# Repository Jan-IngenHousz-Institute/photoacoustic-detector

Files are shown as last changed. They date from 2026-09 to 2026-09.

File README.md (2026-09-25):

# photoacoustic-detector

Photoacoustic detector built from a TLV320ADC6120 audio ADC shield on a
Raspberry Pi Pico (RP2040), an IM73A135 MEMS microphone, and an
actoPulserX4-48V programmable current source driving a 1900 nm LED
(Ushio SMBB1900D-1100-02).

```
kicad/        shield schematic and PCB (Pico + TLV320ADC6120 + mic connector)
doc/          datasheets (ADC, microphone, TI analog-input app note)
firmware/   MicroPython firmware for the Pico
pc-gui/           PySide6 desktop GUI
```

## Wiring

| Function | Pico pin | Notes |
|---|---|---|
| ADC I2C SDA / SCL | GP4 / GP5 | on the shield, 2k2 pull-ups to 3V3 |
| ADC BCLK / FSYNC / SDOUT| GP6 / GP7 / GP8 | Pico is I2S master, 48 kHz 16-bit stereo |
| ADC GPIO1 ("EXT") | GP9 | unused (ADC interrupt output) |
| actopulser SDA / SCL | GP2 / GP3 | J1 pins 7 / 6, Pico internal pull-ups enabled |
| actopulser LDAC | GP14 | J1 pin 8, held low |
| actopulser PULSEa..d | GP10..GP13 | J1 pins 1..4 |
| GND | GND | J1 pin 5 |

Power the actopulser from its own USB-PD supply, not from the Pico. For the
1.4 V LED select 5 V on the actopulser DIP switch: higher rails only heat the
driver MOSFET.

## Firmware (firmware/)

| File | Purpose |
|---|---|
| `TLV320.py` | TLV320ADC6120 driver (presence check, bring-up, gain, status)  |
| `MCP4728.py` | actopulser DAC driver (0.5 mA per LSB into the 2 ohm sense) |
| `pulser.py` | PIO pulse generator locked to the I2S frame clock |
| `lockin.py` | 100 ms block lock-in (viper), raw block de-interleave |
| `main.py` | application: self-test, serial protocol, safety limits |
| `level_meter.py` | stand-alone level meter for first bring-up (`import level_meter`) |

Install: flash a MicroPython UF2 (hold BOOTSEL while plugging in, copy the
UF2 onto the RPI-RP2 drive), then

```
pip install mpremote
mpremote cp firmware/TLV320.py firmware/MCP4728.py firmware/pulser.py firmware/lockin.py firmware/main.py :
mpremote reset
```

`main.py` starts automatically at boot and speaks a line protocol over USB
serial (see the docstring in `firmware/main.py`). Safety rules enforced on
the Pico: LED current limited to 2 A only for pulses of at most 10 us at
1 % duty and to 1 A otherwise, light switched off when the PC stops sending
commands for 5 s, and on any firmware exception.

## PC GUI (pc-gui/)

```
pc-gui\run_gui.bat
```

or, with any Python 3.10+ that imports PySide6 cleanly:

```
pip install -r pc-gui/requirements.txt
python pc-gui/pa_gui.py
```

Note for anaconda users: the anaconda base interpreter fails with
`DLL load failed while importing QtCore` because its root folder ships MSVC
runtime 14.44 DLLs that shadow the newer runtime PySide6 6.11 needs. Use the
python.org interpreter (`py -3.13`, which `run_gui.bat` does), or install
PySide6 from conda-forge inside a conda environment instead of pip.

What it does:

- finds Picos on USB, flags one left in BOOTSEL mode, checks the firmware
  answers, and runs a layered self-test (ADC ack, register test, reset
  defaults, clock lock, active mode, FSYNC present, mic noise floor,
  DAC ack and readback, optional light on/off signal check);
- excitation control with live duty, LED and driver power, and refusal of
  settings outside the LED rating;
- lock-in amplitude and phase strip charts with block averaging, dark
  reference subtraction, dBFS or pascal units, SNR from the spectrum;
- spectrum with markers at the modulation frequency and harmonics, raw
  time trace and pulse-synchronous average;
- frequency sweep to locate the acoustic resonance of the cell;
- CSV logging with the full settings context, notes, config save/load.

## Measurement principle

The Pico drives the LED with short current pulses at a modulation frequency
that divides 48 kHz. A PIO state machine derives the pulse timing from the
I2S word clock, so every pulse falls on the same sample index and the
lock-in phase is stable. Each 100 ms block of ADC samples holds a whole
number of modulation periods; its single-bin DFT gives amplitude and phase
of the photoacoustic response, which the PC averages, plots and logs.

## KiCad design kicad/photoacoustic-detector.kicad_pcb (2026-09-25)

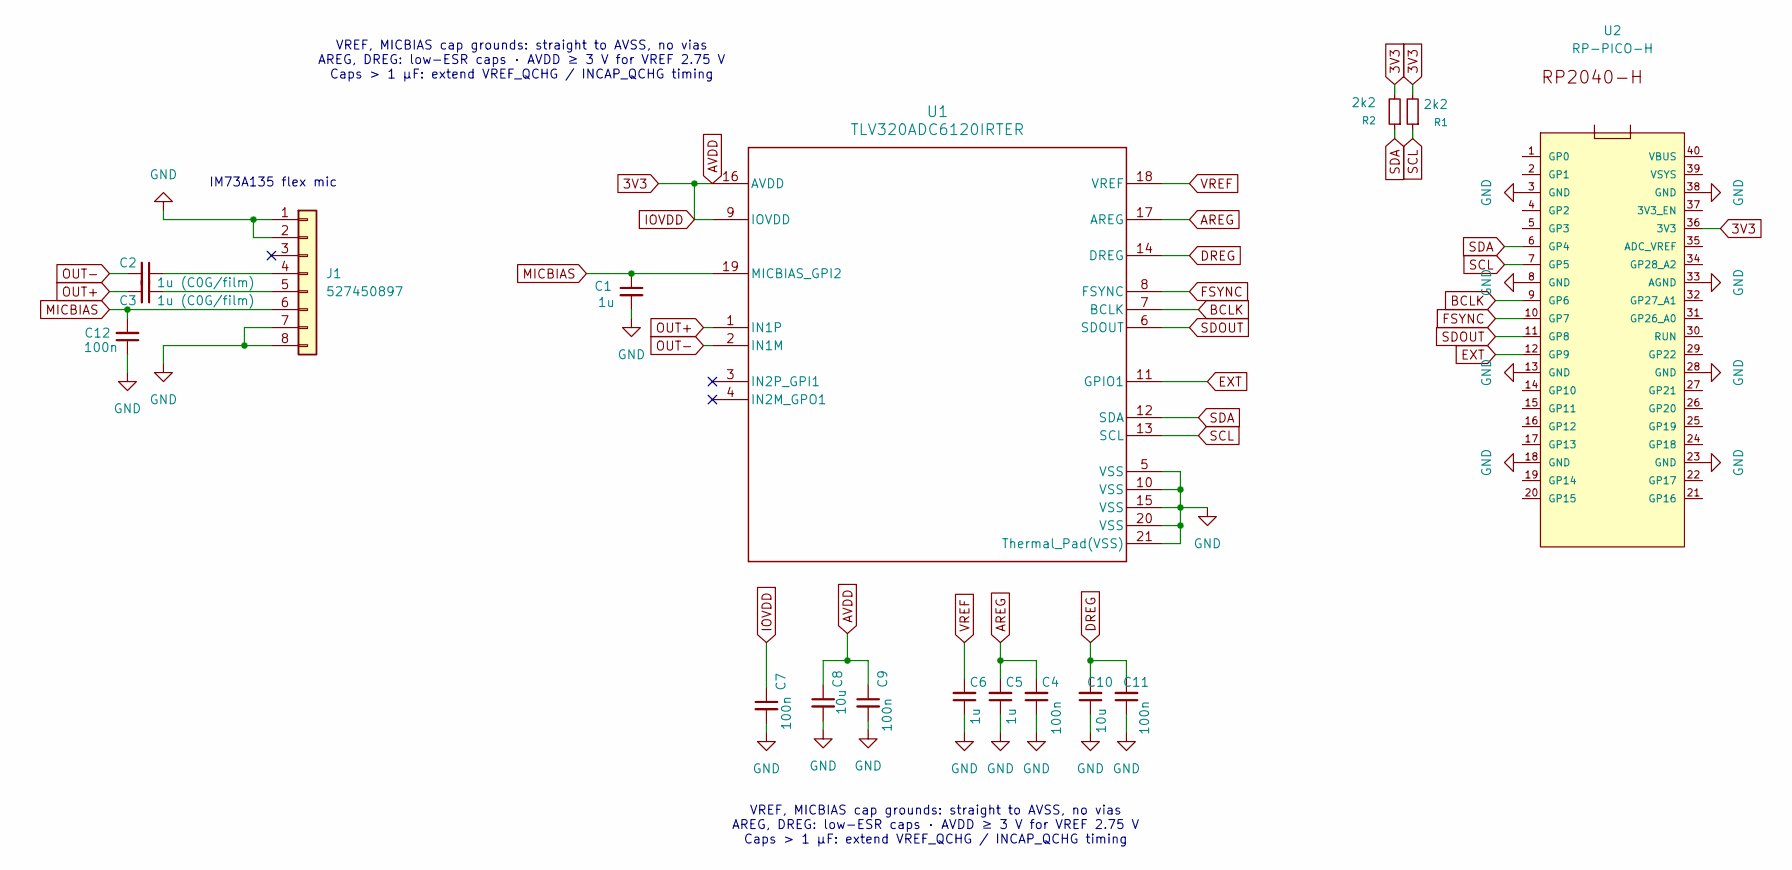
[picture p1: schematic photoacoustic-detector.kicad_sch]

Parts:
C1, C5, C6: 1u; C_0201_0603Metric_Pad0.64x0.40mm_HandSolder
C2, C3: 1u (C0G/film); C_0201_0603Metric_Pad0.64x0.40mm_HandSolder
C4, C7, C9, C11, C12: 100n; C_0201_0603Metric_Pad0.64x0.40mm_HandSolder
C8, C10: 10u; C_0201_0603Metric_Pad0.64x0.40mm_HandSolder
J1: 527450897; CONN_527450897_MOL
R1, R2: 2k2; R_0201_0603Metric_Pad0.64x0.40mm_HandSolder
U1: TLV320ADC6120IRTER; TLV320ADC6120
U2: RP-PICO-H; RP2040-PICO

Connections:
3V3: C7.1, C8.1, C9.1, R1.2, R2.2, U1.9 (IOVDD), U1.16 (AVDD), U2.36 (3V3)
AREG: C4.2, C5.2, U1.17 (AREG)
BCLK: U1.7 (BCLK), U2.9 (GP6)
DREG: C10.2, C11.2, U1.14 (DREG)
EXT: U1.11 (GPIO1), U2.12 (GP9)
FSYNC: U1.8 (FSYNC), U2.10 (GP7)
GND: C1.2, C4.1, C5.1, C6.1, C7.2, C8.2, C9.2, C10.1, C11.1, C12.1, J1.1, J1.2, J1.7, J1.8, U1.5 (VSS), U1.10 (VSS), U1.15 (VSS), U1.20 (VSS), U1.21 (Thermal_Pad(VSS)), U2.3 (GND), U2.8 (GND), U2.13 (GND), U2.18 (GND), U2.23 (GND), U2.28 (GND), U2.33 (AGND), U2.38 (GND)
MICBIAS: C1.1, C12.2, J1.6, U1.19 (MICBIAS_GPI2)
unnamed: C2.1, J1.4
unnamed: C3.1, J1.5
OUT+: C3.2, U1.1 (IN1P)
OUT-: C2.2, U1.2 (IN1M)
SCL: R1.1, U1.13 (SCL), U2.7 (GP5)
SDA: R2.1, U1.12 (SDA), U2.6 (GP4)
SDOUT: U1.6 (SDOUT), U2.11 (GP8)
VREF: C6.2, U1.18 (VREF)

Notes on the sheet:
IM73A135 flex mic
VREF, MICBIAS cap grounds: straight to AVSS, no vias AREG, DREG: low-ESR caps · AVDD ≥ 3 V for VREF 2.75 V Caps > 1 µF: extend VREF_QCHG / INCAP_QCHG timing

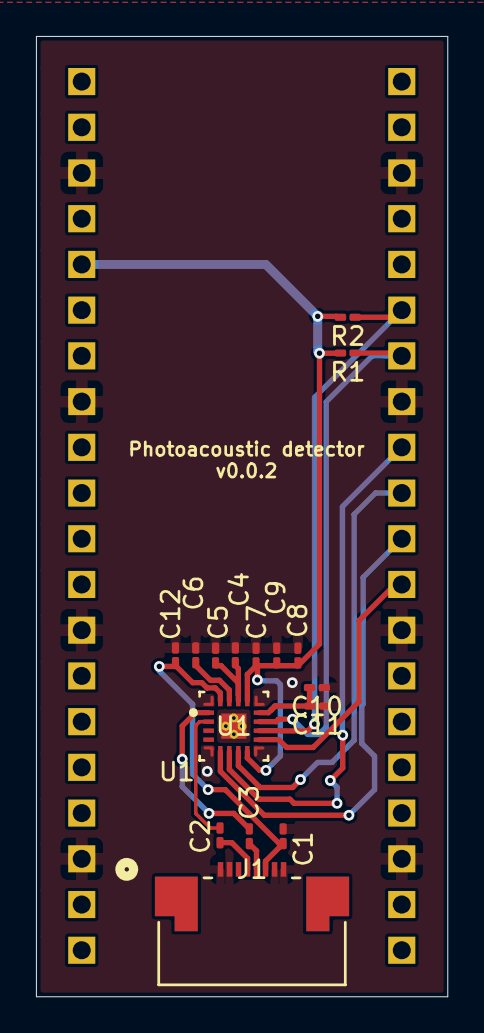
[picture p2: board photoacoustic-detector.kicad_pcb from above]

Board: 2 copper layers, 22.8 x 53.4 mm, 17 parts (1 on the bottom side), 16 nets.

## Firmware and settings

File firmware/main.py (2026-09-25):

"""
main.py - photoacoustic detector firmware for the RP2040 Pico.

Hardware (see kicad/ and the actoPulserX4-48V project):
    ADC TLV320ADC6120   I2C0  GP4 SDA / GP5 SCL      I2S GP6 BCLK, GP7 FSYNC, GP8 SDOUT
    actopulser MCP4728  I2C1  GP2 SDA / GP3 SCL      LDAC GP14 (held low)
    actopulser PULSEa-d GP10..GP13 (PIO pulser locked to FSYNC)
    Pico onboard LED    GP25

Every 100 ms block (4800 frames at 48 kHz) the Pico computes the lock-in
I/Q at the modulation frequency and reports it as one JSON line. Every
`burst` blocks it also sends the raw channel-1 samples of the last block
(base64 int16) so the PC can draw a spectrum and a time trace.

Line protocol over USB serial (commands are plain text, replies are JSON):
    id                        -> {"type":"id", ...}
    status                    -> {"type":"status", ...}
    selftest                  -> {"type":"selftest","results":[...]}
    set <key> <value>         -> {"type":"ack","key":..,"value":..}
        keys: freq (Hz), width (us), current (mA), channel (0-3), gain (dB),
              burst (blocks between raw bursts, 0 = off), heartbeat (s, 0 = off)
    light on|off              -> ack           (LED current + pulses)
    start | stop              -> ack           (data streaming)
    ping                      -> keeps the heartbeat alive
    dump                      -> {"type":"regs", ...}   (ADC page 0)
Unsolicited:
    {"type":"data", ...}  {"type":"burst", ...}  {"type":"log", ...}  {"type":"error", ...}

Safety: the LED (Ushio SMBB1900D) is rated 1 A continuous and 2 A only for
<= 10 us pulses at <= 1 % duty. Limits are enforced here as well as on the PC,
the light is switched off if the PC stops sending commands (heartbeat), and
on any unhandled exception.
"""

import sys
import select
import time
import json
import binascii
from machine import I2C, I2S, Pin

import TLV320
import MCP4728
import pulser
import lockin

FW_NAME = "pa-detector"
FW_VERSION = "0.2.0"

# ---- pin map --------------------------------------------------------------
PIN_ADC_SDA, PIN_ADC_SCL = 4, 5
PIN_BCLK, PIN_FSYNC, PIN_SDOUT = 6, 7, 8
PIN_DAC_SDA, PIN_DAC_SCL, PIN_LDAC = 2, 3, 14
PULSE_PINS = (10, 11, 12, 13)          # actopulser PULSEa..d
PIN_LED = 25

# ---- audio ----------------------------------------------------------------
FS = 48000
BLOCK = 4800                           # frames per block = 100 ms
BITS = 16

# ---- LED / driver limits ----------------------------------------------------
MAX_MA = 2000.0                        # absolute maximum (10 us, 1 % duty)
MAX_MA_DC = 1000.0                     # otherwise
MAX_PULSE_US_FOR_2A = 10.0
MAX_DUTY_FOR_2A = 0.01
MIN_WIDTH_US = 1.0
MAX_WIDTH_US = 20.0                    # must stay below one frame (20.8 us)
MIN_FREQ = 10
DEFAULT_HEARTBEAT_S = 5


def allowed_current_ma(freq, width_us):
    duty = freq * width_us * 1e-6
    if width_us <= MAX_PULSE_US_FOR_2A and duty <= MAX_DUTY_FOR_2A:
        return MAX_MA
    return MAX_MA_DC


def valid_freq(freq):
    """f_mod must divide fs and one block must hold whole periods."""
    if freq < MIN_FREQ or FS % freq:
        return False
    return BLOCK % (FS // freq) == 0


class App:
    def __init__(self):
        self.led = Pin(PIN_LED, Pin.OUT, value=0)
        self.rx = ""
        self.poll = select.poll()
        self.poll.register(sys.stdin, select.POLLIN)

        # settings
        self.freq = 1000
        self.width_us = 10.0
        self.current_ma = 0.0
        self.channel = 0
        self.gain_db = 12.0
        self.light = False
        self.streaming = True
        self.burst_every = 10
        self.heartbeat_s = DEFAULT_HEARTBEAT_S
        self.last_cmd = time.ticks_ms()
        self.seq = 0
        self.t0 = time.ticks_ms()

        # hardware state
        self.adc_ok = False
        self.adc_defaults = None
        self.dac_ok = False
        self.i2s = None
        self.last = None
        self.status_cache = {}

        self.buf = bytearray(BLOCK * 4)               # int16 stereo frames
        self.left = bytearray(BLOCK * 2)              # int16 channel 1
        self.li = lockin.LockIn(FS // self.freq)

    # ---- output helpers -----------------------------------------------------
    def send(self, obj):
        sys.stdout.write(json.dumps(obj))
        sys.stdout.write("\n")

    def log(self, level, msg):
        self.send({"type": "log", "level": level, "msg": msg})

    def error(self, msg):
        self.send({"type": "error", "msg": msg})

    # ---- hardware ------------------------------------------------------------
    def init_hw(self):
        # ADC
        self.i2c0 = I2C(0, sda=Pin(PIN_ADC_SDA), scl=Pin(PIN_ADC_SCL), freq=400_000)
        self.adc = TLV320.TLV320ADC6120(self.i2c0)
        self.adc_ok = self.adc.detect()
        if self.adc_ok:
            self.adc.reset()
            self.adc_defaults = self.adc.verify()
            self.adc.begin(bits=BITS, gain_db=self.gain_db)
        else:
            self.log("error", "TLV320ADC6120 not found on I2C0")

        # I2S master, always started so FSYNC exists for the pulser
        self.i2s = I2S(0, sck=Pin(PIN_BCLK), ws=Pin(PIN_FSYNC), sd=Pin(PIN_SDOUT),
                       mode=I2S.RX, bits=BITS, format=I2S.STEREO, rate=FS,
                       ibuf=BLOCK * 4 * 4)

        # actopulser DAC (3.3 V I2C into a 5 V MCP4728 works in practice)
        Pin(PIN_DAC_SDA, Pin.IN, Pin.PULL_UP)
        Pin(PIN_DAC_SCL, Pin.IN, Pin.PULL_UP)
        self.i2c1 = I2C(1, sda=Pin(PIN_DAC_SDA), scl=Pin(PIN_DAC_SCL), freq=100_000)
        self.ldac = Pin(PIN_LDAC, Pin.OUT, value=0)
        self.dac = MCP4728.MCP4728(self.i2c1)
        try:
            self.dac_ok = self.dac.present()
            if self.dac_ok:
                self.dac.off_all()
        except OSError:
            self.dac_ok = False
        if not self.dac_ok:
            self.log("warn", "actopulser MCP4728 not found on I2C1")

        # pulser (idle)
        self.pulser = pulser.Pulser(PULSE_PINS[self.channel], FS // self.freq, self.width_us)
        for p in PULSE_PINS:
            if p != PULSE_PINS[self.channel]:
                Pin(p, Pin.IN)

        time.sleep_ms(50)
        self.refresh_status()

    def refresh_status(self):
        if self.adc_ok:
            try:
                self.status_cache = self.adc.status()
            except OSError:
                self.status_cache = {"clock_ok": False, "mode": "i2c error"}
        else:
            self.status_cache = {"clock_ok": False, "mode": "no adc"}

    # ---- light control --------------------------------------------------------
    def apply_current(self):
        if not self.dac_ok:
            return
        code = MCP4728.MCP4728.ma_to_code(self.current_ma) if self.light else 0
        self.dac.write(self.channel, code)

    def set_light(self, on):
        if on and not self.dac_ok:
            raise ValueError("actopulser not present")
        if on:
            self.light = True
            self.apply_current()
            self.pulser.configure(FS // self.freq, self.width_us)
            self.pulser.start()
        else:
            self.pulser.stop()
            self.light = False
            self.apply_current()
        self.led.value(1 if self.light else 0)

    def clamp_current(self):
        lim = allowed_current_ma(self.freq, self.width_us)
        if self.current_ma > lim:
            self.current_ma = lim
            self.log("warn", "current clamped to %.0f mA by LED duty limit" % lim)
            self.apply_current()

    # ---- commands ---------------------------------------------------------------
    def handle(self, line):
        self.last_cmd = time.ticks_ms()
        parts = line.strip().split()
        if not parts:
            return
        cmd = parts[0].lower()
        try:
            if cmd == "ping":
                return
            if cmd == "id":
                self.send({"type": "id", "fw": FW_NAME, "version": FW_VERSION,
                           "fs": FS, "block": BLOCK, "bits": BITS,
                           "adc": self.adc_ok, "dac": self.dac_ok,
                           "ma_per_lsb": MCP4728.MA_PER_LSB,
                           "pulse_pins": PULSE_PINS})
            elif cmd == "status":
                self.refresh_status()
                self.send(self.status_obj())
            elif cmd == "selftest":
                self.send({"type": "selftest", "results": self.selftest()})
            elif cmd == "start":
                self.streaming = True
                self.send({"type": "ack", "key": "stream", "value": True})
            elif cmd == "stop":
                self.streaming = False
                self.send({"type": "ack", "key": "stream", "value": False})
            elif cmd == "light":
                on = len(parts) > 1 and parts[1].lower() in ("on", "1", "true")
                self.set_light(on)
                self.send({"type": "ack", "key": "light", "value": self.light})
            elif cmd == "set" and len(parts) >= 3:
                self.set_param(parts[1].lower(), parts[2])
            elif cmd == "dump":
                regs = {}
                if self.adc_ok:
                    for r in range(0x78):
                        regs["0x%02X" % r] = self.adc.read_reg(r)
                self.send({"type": "regs", "regs": regs})
            else:
                self.error("unknown command: " + line.strip())
        except (ValueError, OSError) as e:
            self.error("%s: %s" % (cmd, e))

    def set_param(self, key, val):
        if key == "freq":
            f = int(float(val))
            if not valid_freq(f):
                raise ValueError("freq must divide 48000 and 4800/period must be integer")
            self.freq = f
            self.li.set_period(FS // f)
            self.pulser.configure(period_frames=FS // f)
            self.clamp_current()
            self.send({"type": "ack", "key": key, "value": self.freq})
        elif key == "width":
            w = float(val)
            if not MIN_WIDTH_US <= w <= MAX_WIDTH_US:
                raise ValueError("width %.1f..%.1f us" % (MIN_WIDTH_US, MAX_WIDTH_US))
            self.width_us = w
            self.pulser.configure(width_us=w)
            self.clamp_current()
            self.send({"type": "ack", "key": key, "value": self.pulser.actual_width_us()})
        elif key == "current":
            ma = float(val)
            if ma < 0:
                raise ValueError("current >= 0")
            lim = allowed_current_ma(self.freq, self.width_us)
            if ma > lim:
                raise ValueError("current above LED limit of %.0f mA for this width/duty" % lim)
            self.current_ma = ma
            self.apply_current()
            self.send({"type": "ack", "key": key,
                       "value": MCP4728.MCP4728.code_to_ma(MCP4728.MCP4728.ma_to_code(ma))})
        elif key == "channel":
            ch = int(val)
            if not 0 <= ch <= 3:
                raise ValueError("channel 0..3")
            was = self.light
            if was:
                self.set_light(False)
            self.channel = ch
            self.pulser.set_pin(PULSE_PINS[ch])
            if was:
                self.set_light(True)
            self.send({"type": "ack", "key": key, "value": ch})
        elif key == "gain":
            g = float(val)
            if not self.adc_ok:
                raise ValueError("no ADC")
            self.adc.set_gain(1, g)
            self.gain_db = round(g * 2) / 2
            self.send({"type": "ack", "key": key, "value": self.gain_db})
        elif key == "burst":
            self.burst_every = max(0, int(val))
            self.send({"type": "ack", "key": key, "value": self.burst_every})
        elif key == "heartbeat":
            self.heartbeat_s = max(0, int(val))
            self.send({"type": "ack", "key": key, "value": self.heartbeat_s})
        else:
            raise ValueError("unknown key " + key)

    def status_obj(self):
        return {"type": "status", "adc": self.status_cache, "adc_ok": self.adc_ok,
                "dac_ok": self.dac_ok, "freq": self.freq, "width_us": self.pulser.actual_width_us(),
                "current_ma": self.current_ma, "channel": self.channel, "gain_db": self.gain_db,
                "light": self.light, "streaming": self.streaming, "burst": self.burst_every,
                "heartbeat_s": self.heartbeat_s, "seq": self.seq}

    # ---- self test --------------------------------------------------------------
    def selftest(self):
        res = []

        def add(name, status, detail=""):
            res.append({"name": name, "status": status, "detail": detail})

        # ADC presence
        try:
            devs = self.i2c0.scan()
            add("adc_i2c_ack", "pass" if TLV320.I2C_ADDR in devs else "fail",
                "I2C0 devices: " + ", ".join("0x%02X" % d for d in devs))
        except OSError as e:
            add("adc_i2c_ack", "fail", str(e))
        add("adc_register_test", "pass" if self.adc_ok and self.adc.detect() else "fail",
            "page register write/read-back")
        if self.adc_defaults is None:
            add("adc_reset_defaults", "skip", "ADC not initialised")
        else:
            add("adc_reset_defaults", "pass" if not self.adc_defaults else "fail",
                "mismatches: %s" % self.adc_defaults)

        # clocks and mode
        self.refresh_status()
        st = self.status_cache
        add("adc_clock_detect", "pass" if st.get("clock_ok") else "fail",
            "fs=%s ratio=%s" % (st.get("fs"), st.get("bclk_ratio")))
        add("adc_active_mode", "pass" if "channel(s) on" in str(st.get("mode")) else "fail",
            "mode=%s ch1=%s" % (st.get("mode"), st.get("ch1_on")))

        # FSYNC toggling (needed by the pulser)
        p = Pin(PIN_FSYNC)
        seen = 0
        for _ in range(400):
            seen |= 1 << p.value()
        add("fsync_toggling", "pass" if seen == 3 else "fail",
            "I2S word clock observed on GP%d" % PIN_FSYNC)

        # microphone noise floor
        if self.last is None:
            add("mic_noise_floor", "skip", "no audio block yet")
        else:
            rms_db = lockin.LockIn.dbfs(self.last[4])
            if rms_db < -95:
                s, d = "fail", "input silent (%.1f dBFS): mic dead, unpowered or open" % rms_db
            elif rms_db > -20:
                s, d = "warn", "very loud (%.1f dBFS): overload, oscillation or hum" % rms_db
            else:
                s, d = "pass", "%.1f dBFS at %.1f dB gain" % (rms_db, self.gain_db)
            add("mic_noise_floor", s, d)
            add("adc_overload", "pass" if self.last[5] < 32000 else "warn",
                "peak %d / 32767" % self.last[5])

        # actopulser DAC
        try:
            devs = self.i2c1.scan()
            add("dac_i2c_ack", "pass" if MCP4728.I2C_ADDR in devs else "fail",
                "I2C1 devices: " + ", ".join("0x%02X" % d for d in devs))
        except OSError as e:
            add("dac_i2c_ack", "fail", str(e))
        if self.dac_ok:
            try:
                rb = self.dac.read()
                exp = MCP4728.MCP4728.ma_to_code(self.current_ma) if self.light else 0
                got = rb[self.channel]["code"]
                add("dac_readback", "pass" if got == exp else "fail",
                    "channel %d code %d (expected %d), vref=%d gain=%d" %
                    (self.channel, got, exp, rb[self.channel]["vref"], rb[self.channel]["gain"]))
            except OSError as e:
                add("dac_readback", "fail", str(e))
        else:
            add("dac_readback", "skip", "actopulser not present")

        add("pulser_state", "pass", "PIO %s on GP%d, period %d frames, width %.1f us" %
            ("running" if self.pulser.active else "idle", self.pulser.pin_no,
             self.pulser.period, self.pulser.actual_width_us()))
        add("light_functional", "skip", "run the light on/off check from the PC")
        return res

    # ---- main loop ---------------------------------------------------------------
    def poll_cmds(self):
        while self.poll.poll(0):
            c = sys.stdin.read(1)
            if not c:
                break
            if c in "\r\n":
                if self.rx:
                    line, self.rx = self.rx, ""
                    self.handle(line)
            else:
                self.rx += c
                if len(self.rx) > 200:
                    self.rx = ""

    def check_heartbeat(self):
        if self.light and self.heartbeat_s and \
                time.ticks_diff(time.ticks_ms(), self.last_cmd) > self.heartbeat_s * 1000:
            self.set_light(False)
            self.log("warn", "heartbeat lost: light switched off")

    def send_burst(self):
        lockin.deinterleave_left(self.buf, self.left, BLOCK)
        b64 = binascii.b2a_base64(self.left)[:-1].decode()
        self.send({"type": "burst", "seq": self.seq, "n": BLOCK, "fs": FS,
                   "period": self.li.period, "b64": b64})

    def run(self):
        self.init_hw()
        self.send({"type": "id", "fw": FW_NAME, "version": FW_VERSION, "fs": FS,
                   "block": BLOCK, "bits": BITS, "adc": self.adc_ok, "dac": self.dac_ok,
                   "ma_per_lsb": MCP4728.MA_PER_LSB, "pulse_pins": PULSE_PINS})
        while True:
            n = self.i2s.readinto(self.buf)
            if n < len(self.buf):
                self.poll_cmds()
                continue
            self.seq += 1
            i, q, amp, ph, rms, peak = self.li.process(self.buf, BLOCK)
            self.last = (i, q, amp, ph, rms, peak)
            if self.seq % 10 == 0:
                self.refresh_status()
            if self.streaming:
                self.send({"type": "data", "seq": self.seq,
                           "t": time.ticks_diff(time.ticks_ms(), self.t0),
                           "i": i, "q": q, "amp": amp, "amp_db": lockin.LockIn.dbfs(amp),
                           "ph": ph, "rms": rms, "rms_db": lockin.LockIn.dbfs(rms),
                           "peak": peak, "ovl": peak >= 32000,
                           "clk": bool(self.status_cache.get("clock_ok")),
                           "freq": self.freq, "light": self.light,
                           "ma": self.current_ma if self.light else 0.0,
                           "gain": self.gain_db})
                if self.burst_every and self.seq % self.burst_every == 0:
                    self.send_burst()
            if not self.light:
                self.led.value(self.seq % 10 < 5)
            self.poll_cmds()
            self.check_heartbeat()


app = App()
try:
    app.run()
except KeyboardInterrupt:
    pass
except Exception as e:
    try:
        app.error("fatal: %r" % e)
    except Exception:
        pass
    raise
finally:
    try:
        app.set_light(False)
    except Exception:
        pass
    try:
        if app.dac_ok:
            app.dac.off_all()
    except Exception:
        pass

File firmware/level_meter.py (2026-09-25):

"""
level_meter.py - stand-alone bring-up test for the shield (no PC software).

1. Checks that the TLV320ADC6120 answers on I2C (GP4 = SDA, GP5 = SCL).
2. Brings the ADC up: I2S slave, channel 1 differential mic input, 48 kHz.
3. Starts the Pico I2S master on GP6 (BCLK), GP7 (FSYNC), GP8 (SDOUT).
4. Prints the ADC clock/mode status and a running signal level of channel 1.

Run it from the REPL with:  import level_meter
The onboard LED blinks fast if the ADC is missing, slow while running.
"""

from machine import I2C, I2S, Pin
from array import array
import math
import time

import TLV320

PIN_SDA = 4
PIN_SCL = 5
PIN_BCLK = 6      # I2S sck  (ws must be sck + 1 on the RP2040 port)
PIN_FSYNC = 7     # I2S ws
PIN_SDOUT = 8     # I2S sd (input)
PIN_LED = 25      # Pico H onboard LED

SAMPLE_RATE = 48_000
BITS = 32                 # 32-bit stereo -> BCLK/FSYNC ratio 64, supported by the ADC
GAIN_DB = 12              # analog gain, 0..42 dB
FRAMES = 2048             # frames per read (stereo -> 2 samples per frame)

led = Pin(PIN_LED, Pin.OUT)


def blink_forever(period_ms):
    while True:
        led.toggle()
        time.sleep_ms(period_ms)


def level_dbfs(buf, step=2, offset=0):
    """RMS and peak of every `step`-th sample, in dBFS (32-bit full scale)."""
    fs = 2147483647.0
    acc = 0.0
    peak = 0
    n = 0
    for i in range(offset, len(buf), step):
        v = buf[i]
        acc += float(v) * v
        a = -v if v < 0 else v
        if a > peak:
            peak = a
        n += 1
    rms = math.sqrt(acc / n) if n else 0.0
    to_db = lambda x: 20 * math.log10(x / fs) if x > 0 else -200.0
    return to_db(rms), to_db(peak)


i2c = I2C(0, sda=Pin(PIN_SDA), scl=Pin(PIN_SCL), freq=400_000)
print("I2C devices:", [hex(a) for a in i2c.scan()])

adc = TLV320.TLV320ADC6120(i2c)
if not adc.detect():
    print("TLV320ADC6120 NOT found at 0x%02X" % TLV320.I2C_ADDR)
    blink_forever(100)
print("TLV320ADC6120 found at 0x%02X" % TLV320.I2C_ADDR)

adc.reset()
mismatch = adc.verify()
if mismatch:
    print("warning: unexpected reset values (reg, got, expected):", mismatch)
else:
    print("register defaults match TLV320ADC6120 datasheet")

adc.begin(bits=BITS, gain_db=GAIN_DB)

i2s = I2S(0, sck=Pin(PIN_BCLK), ws=Pin(PIN_FSYNC), sd=Pin(PIN_SDOUT),
          mode=I2S.RX, bits=BITS, format=I2S.STEREO, rate=SAMPLE_RATE,
          ibuf=FRAMES * 2 * (BITS // 8) * 4)

time.sleep_ms(50)
st = adc.status()
print("ADC status:", st)
if not st["clock_ok"]:
    print("warning: ADC did not detect a valid FSYNC/BCLK ratio")

buf = array("i", (0 for _ in range(FRAMES * 2)))
mv = memoryview(buf)

print("streaming channel 1 (left slot)... Ctrl-C to stop")
try:
    t_last = time.ticks_ms()
    while True:
        n = i2s.readinto(mv)
        if n == 0:
            continue
        rms, peak = level_dbfs(buf, step=2, offset=0)
        if time.ticks_diff(time.ticks_ms(), t_last) >= 500:
            t_last = time.ticks_ms()
            led.toggle()
            print("CH1  rms %6.1f dBFS   peak %6.1f dBFS" % (rms, peak))
except KeyboardInterrupt:
    pass
finally:
    i2s.deinit()
    adc.power_down()
    adc.sleep()
    led.off()
    print("stopped, ADC in sleep mode")

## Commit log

2026-09-22 micropython code
    [photoacoustic-detector.kicad_pcb, photoacoustic-detector.kicad_sch]
2026-09-25 updated the kicad and added the pc-gui
    [photoacoustic-detector.kicad_pcb, photoacoustic-detector.kicad_sch]
